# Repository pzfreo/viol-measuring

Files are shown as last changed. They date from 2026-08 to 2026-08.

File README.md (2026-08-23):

# A tap-testing rig that fits your instrument

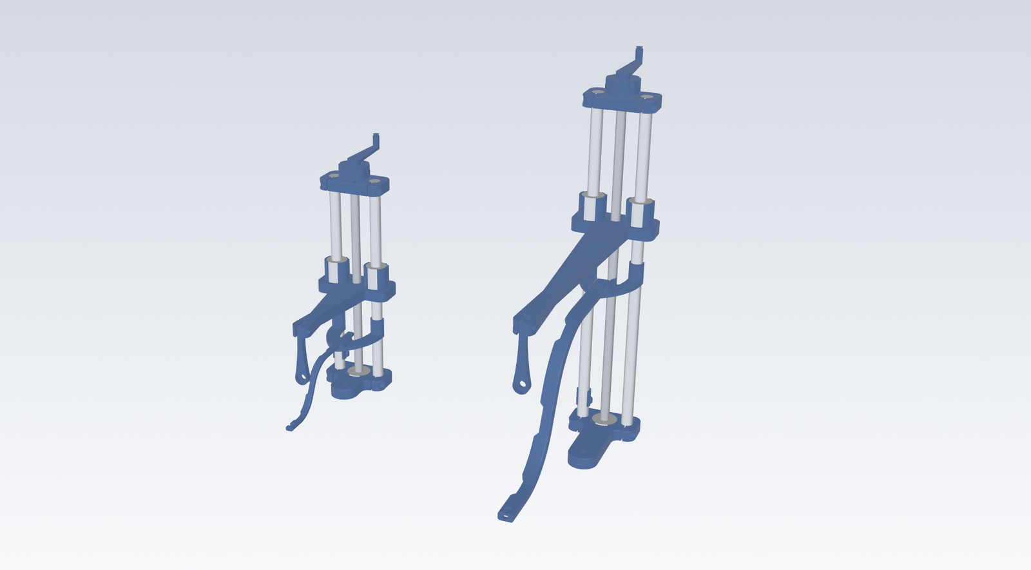
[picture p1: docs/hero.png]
The same rig built for a violin and for a cello


*The same rig, printed for a violin (left) and a cello (right) — same rods,
same bearings, same leadscrew, same clamp hardware. Nothing was redrawn: you
give it the instrument's dimensions and every part follows.*

---

This is [Luca Jost's General Acoustic Measurement Setup][upstream] rebuilt so
that it scales. His rig is a lovely piece of design: a printed column with a
sliding arm, a pendulum hammer that taps the belly at the same speed every
time, and a microphone on a curved arm beside the ribs. It is dimensioned for a
violin.

If you work on violas da gamba, cellos, or anything else with deeper ribs and a
wider lower bout, those dimensions do not fit. This version asks you for the
instrument instead:

```
body length 660    ribs 125    lower bout 380
```

and works out the rest — how far the arm must reach, how high the tap point
sits, how tall the column needs to be, and where the hammer pins.

## Which instrument?

| preset | body | ribs | lower bout | tap point | reach | column |
|---|---|---|---|---|---|---|
| `violin` | 355 | 30 | 208 | 45 up | 106 out | 200 |
| `viola` | 410 | 34 | 240 | 50 | 122 | 200 |
| `treble viol` | 370 | 62 | 230 | 80 | 117 | 250 |
| `tenor viol` | 490 | 88 | 290 | 108 | 147 | 250 |
| `bass viol` | 660 | 125 | 380 | 147 | 192 | 300 |
| `cello` | 755 | 114 | 440 | 139 | 222 | 300 |

All dimensions in mm. Every preset runs on **Luca Jost's hardware** — ⌀10
aluminium rods, an M8 leadscrew, LM10UU linear bearings, 608 thrust bearings,
M4 clamp screws. Only the rod length changes.

The `violin` preset reproduces his original rig. Every part was measured back
off his mesh files and rebuilt to match — if you want to know how closely, and
where it does not, that is in [FIDELITY.md](FIDELITY.md).

The viol figures are mid-range for surviving consort instruments, which vary far
more than the violin family does. If yours differs, see
[Changing the numbers](#changing-the-numbers).

## Making one

You need [uv](https://github.com/astral-sh/uv), or any Python 3.10+ with pip.

```bash
git clone https://github.com/pzfreo/viol-measuring
cd viol-measuring
uv venv --python 3.12 .venv
uv pip install --python .venv/bin/python build123d numpy

.venv/bin/python tools/export_all.py "bass viol"
```

That writes all eleven parts as STL and STEP into `export/bass_viol/`, plus the
whole rig assembled as a single STEP so you can look it over before spending a
weekend printing. It also prints the rig's key dimensions, so you can check them
against your instrument first. Use any preset name from the table; `violin` is
the default.

**Everything prints without support.** The cross-bolt holes are teardrop-shaped
for exactly that reason, and each part is oriented so a flat face is the build
surface. Three parts need a print pause to capture a nut — the exported bill of
materials says which, and when.

## What to buy

**[BOM.md](BOM.md)** has the full list for the cello / bass viol rig: printed
masses, exact bolt lengths, bearing designations and print orientations, all
generated from the model so it cannot drift from the geometry. Regenerate it for
any other instrument:

```bash
.venv/bin/python tools/make_bom.py "tenor viol"
```

The bought-in parts are Luca Jost's [original list][upstream] — two aluminium
guide rods, a threaded rod, linear bearings, two 608 bearings, M4 hardware,
electret microphones and a Behringer UCA-202. His README has purchase links, and
for a larger rig the only change is the length of the rods and the leadscrew.

## One rig for more than one instrument

A bass viol and a cello want **the same rig**: same rods, same leadscrew, same
300 mm column, same plates and carriage. They differ in exactly one thing the
assembled rig cannot already adjust — 30 mm of hammer reach. Everything else is
a setting: tap height is the crank, the microphone arm slides in its fins, and
the holder clips anywhere on the rods.

So build one, and give the arm a pivot hole for each:

```bash
.venv/bin/python tools/export_all.py "bass viol+cello"
```

Move the pin, wind the crank, and it is set for the other instrument.

## Four things worth knowing before you measure

**Bolt it down.** The three counterbored holes in the base are not feet — they
take M3 screws into a board. Free-standing, the violin rig tips under about 48 g
applied to the end of the arm and the cello rig under 56 g; that is a hand
resting on it. This is true of the original rig too, not something the larger
sizes introduced. Bolted to a board it is not close.

**Check your frequency range.** The measurement template that ships with the
original (`ref/upstream/GMS_template.txt`) plots from 200 Hz. A cello's A0 air
mode sits at roughly 93–120 Hz, and a bass viol's will be similar — *below the
bottom of the default plot*. The single most diagnostic low mode would not be on
screen. The 0.3 s sample window is also coarse for a sharp air mode. Both want
changing for anything larger than a viola.

**The hammer hangs on two cone points.** The two M4 × 5 grub screws are not
an afterthought — they *are* the pivot. One threads into each fork prong, and
their tapered tips seat in the rim of the 1.5 mm hole through the hammer's
tail, so the hammer swings on two cones rather than turning on a pin. Wind
them in until it just swings freely. Buy the tapered-tip ones: a flat or cup
point has nothing to seat in.

**This is not a free-free measurement.** The rig lays the instrument on its back
on the bench. Modal work normally supports the instrument on foam or hangs it on
elastic, precisely to avoid the bench damping it. For a violin the difference is
small; for a cello-sized instrument resting its ribs on a bench it is
proportionally larger. Worth one controlled comparison before trusting absolute
numbers at the large end.

## Changing the numbers

If your instrument is not one of the presets, or you have measured your own, one
line does it:

```python
from gams import Instrument, Rig

my_viol = Instrument("my bass", body_length=680, rib_depth=132,
                     arching=24, lower_bout=395)

print(Rig(my_viol).summary())
```

That prints the rig those four numbers imply. Everything else — reach, tap
height, column height, arm section — follows.

The fits are adjustable too, if your printer runs tight or loose. The one that
matters most is the slot the microphone arm slides in: the original ships the
arm in ±0.05, ±0.10 and ±0.15 mm widths for exactly this reason. Here it is a
single number (`fits.arm_slot`, default 0.06 mm) rather than four models.

## Before you print: what is proven and what is not

**The violin preset is his design**, built and iterated in practice. Everything
below applies to the larger sizes.

**None of the larger presets has been printed or used.** How the arm section
grows with reach, how the microphone arm's bend stretches, where the hammer
pins — none of that is in his design, because his design is for a violin. They
are a considered starting point, not a proven rig.

**The larger rigs are soft, and I have not fixed it.** At a cello's reach the
printed slider arm carries 91% of the movement at the tap point, and the rig's
first mode lands near 52 Hz — below a cello's A0 at about 100 Hz, so the rig can
ring inside the band you are trying to measure. What would help is a deeper arm
section, since stiffness goes as the cube of depth. See
[FIDELITY.md](FIDELITY.md#the-hardware-ladder-and-why-it-is-gone) for the
working, including a rule this repo used to have that did not survive it.

**There is no published rig at this size to check against.** Joseph Curtin's
[Impulse Measurement Rig][curtin-rig], the reference instrument in this field,
covers *"violins and violas of any size"* and does not do cellos.

## Sources and further reading

If you are new to this, start with Gough — it is the clearest overview of what
you are actually measuring and why.

**Violin family acoustics**

- Colin Gough, [*Violin Acoustics*][gough-at], Acoustics Today (2016) —
  [PDF][gough-pdf], [supplementary text][gough-supp], [media][gough-media]
- Colin Gough, [*Violin acoustics: an introduction and recent
  developments*][gough-musica] (MusICA seminar); his site: [colingough.com][gough-site]
- Jim Woodhouse, [*Euphonics: the science of musical
  instruments*][euphonics] — the online reference work; see especially
  [signature modes and formants][euphonics-modes] and [experimental modal
  analysis][euphonics-ema]
- George Bissinger's papers and the Strad3D datasets: [strad3d.org][strad3d]
- [Modal analysis of violins and cellos][asa-cello], Acoustical Society of
  America — one of the few sources giving cello mode frequencies

**Measurement practice**

- [VSA-Oberlin Acoustics Workshop][oberlin] and its
  [YouTube channel][oberlin-yt] — the annual gathering where most of this is
  worked out
- Joseph Curtin, [Impulse Measurement Rig][curtin-rig] — the commercial
  reference rig; useful for what it specifies (a few-gram impulse hammer, an
  omnidirectional condenser mic, meaningful data to 7 kHz)
- [ObiApp][obiapp], the free analysis software by Chris Rogers and Joseph
  Curtin that goes with it
- George Stoppani's [modal analysis software][stoppani] — acquisition, mode
  fitting, mode shapes and animation; widely used by makers
- Martin Schleske on [modal analysis][schleske] and [sound analysis
  method][schleske-method]
- [Support conditions for free boundary-condition modal testing][free-free] —
  why foam and elastic suspension are the norm

There is more detail, including the numbers behind the frequency-range warning
above, in [`REFERENCE.md`](REFERENCE.md).

## Credit

The design is **Luca Jost's**. The column, the pendulum hammer, the sliding arm,
the curved microphone arm, the split clamps, the choice of hardware — all of it
is his, and it is a genuinely good piece of design that repaid careful
measurement. This repository only re-expresses it as parameters so it can be
made larger.

His original: [luca-jost-violins/General-Acoustic-Measurement-Setup][upstream].
Please start there, and use his README for the parts list and purchase links.

## Licence

MIT, matching the original. See [LICENSE](LICENSE).

*(A note for Luca, if you find this: the `LICENSE` in your repository still has
the placeholder `[year] [fullname]` where the copyright line should be — that is
[issue #1][upstream-issue] on your repo. Filling it in would make it easier for
people to build on your work with confidence.)*

[upstream]: https://github.com/luca-jost-violins/General-Acoustic-Measurement-Setup
[upstream-issue]: https://github.com/luca-jost-violins/General-Acoustic-Measurement-Setup/issues/1
[gough-at]: https://acousticstoday.org/violin-acoustics-colin-e-gough/
[gough-pdf]: https://acousticstoday.org/wp-content/uploads/2016/06/Gough.pdf
[gough-supp]: https://acousticstoday.org/supplementary-text-violinacoustics-colin-e-gough/
[gough-media]: https://acousticstoday.org/violin-acoustics-media/
[gough-musica]: https://www.musica.ed.ac.uk/archive/2017/colin-gough/
[gough-site]: http://colingough.com/
[euphonics]: https://euphonics.org/
[euphonics-modes]: https://euphonics.org/5-3-signature-modes-and-formants/
[euphonics-ema]: https://euphonics.org/10-5-experimental-modal-analysis/
[strad3d]: https://strad3d.org/articles.html
[asa-cello]: https://acoustics.org/pressroom/httpdocs/135th/rossing.htm
[oberlin]: https://josephcurtinstudios.com/research/oberlin-workshop/
[oberlin-yt]: https://www.youtube.com/@oberlinacousticsworkshop9137
[curtin-rig]: https://josephcurtinstudios.com/research/measurement-rig/
[obiapp]: https://sites.google.com/view/oberlinacoustics/home
[stoppani]: http://www.stoppani.co.uk/Technical.htm
[schleske]: https://www.schleske.de/en/research/introduction-violin-acoustics/modal-analysis.html
[schleske-method]: https://www.schleske.de/en/research/introduction-violin-acoustics/sound-analysis/method.html
[free-free]: https://www.osti.gov/servlets/purl/1266149

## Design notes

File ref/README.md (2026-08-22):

# Reference material

`upstream/` holds Luca Jost's original `.3mf` parts, vendored unchanged from
[General-Acoustic-Measurement-Setup][upstream] (MIT). Everything in this
rebuild was measured from these, and the generated fingerprint suites in
`tests/fingerprint/` are checked against them.

Three directories are **not** in the repository because they are derived from
`upstream/` and are large. Regenerate them when you need them:

```bash
# STL copies of the reference parts, used to generate the fingerprint suites
PYTHONPATH=tools python tools/3mf_to_stl.py

# four-view renders of each reference part
PYTHONPATH=tools python tools/render_mesh.py

# cross-sections through a part, for reading dimensions off it
PYTHONPATH=tools python tools/section_mesh.py "ref/upstream/01 Base.3mf" Z "0.5,2,5,8" out.png
```

The other tools in `tools/` read the same references directly:

| tool | what it does |
|---|---|
| `probe_3mf.py` | bounding boxes and mesh statistics |
| `features.py` | fits circles to a cross-section — hole centres and diameters |
| `occupancy.py` | material-vs-void map on a plane, when an outline is ambiguous |
| `diff_mesh.py` | where a rebuilt part differs from its reference |
| `volume_diff.py` | localises that difference by layer |
| `arcfit.py` | decomposes a section outline into lines and arcs |
| `revolve_profile.py` | recovers the profile of a turned part |
| `stability.py` | centre of gravity and tipping loads for an assembly |

[upstream]: https://github.com/luca-jost-violins/General-Acoustic-Measurement-Setup

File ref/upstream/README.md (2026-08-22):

# General-Acoustic-Measurement-Setup

This is the universal acoustic measurement setup for musical instrument makers. Currently supported instruments are: the violin, the viola

This repository will provide .3mf files for FDM-3D-printing of the necessary parts, a list of additional parts to buy and guides for making and using the setup.

Here is a complete list of the required parts. Please note that I haven't checked for best price or availability. This is just to help you with more details about the parts. Also for some of the electronic components I could not find exact products as of yet, so there are some questionmarks around the links:

| Part | Count | Link (US) | Link (GER) |
| --- | ----- | ---| --- |
| 10 mm Diameter, 200 mm long aluminium rods | 2 | [here](https://www.amazon.com/dp/B0BNQ4Q1QQ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)  |[here](https://www.amazon.de/dp/B07K7MM3NH?ref_=ppx_hzsearch_conn_dt_b_fed_asin_title_1&th=1) |
| 210 mm long M8 threaded rod | 1 | [here](https://www.amazon.com/dp/B08FQL7LXV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)  | [here](https://www.amazon.de/Lun-Fix-Gewindestange-Festigkeitsklasse-Gewindestift/dp/B0C8HVDMVJ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) |
| 10 mm ID, 19 mm OD linear bearings | 2 | [here](https://www.amazon.com/-/de/dp/B0D4J1PK9P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)  | [here](https://www.amazon.de/dp/B09DFGZD8N?ref_=ppx_hzsearch_conn_dt_b_fed_asin_title_1) |
| 8 mm ID, 22 mm OD ball bearings | 2 | [here](https://www.amazon.com/-/de/dp/B08L8795LS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)  | [here](https://www.amazon.de/dp/B08K936Y1Z?ref_=ppx_hzsearch_conn_dt_b_fed_asin_title_1) |
| 10 mm long M4 cylinder head bolts | 4 | [here](https://www.amazon.com/-/de/dp/B0BNHGCBGP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)  | [here](https://www.amazon.de/dp/B07YWD33YT?ref_=ppx_hzsearch_conn_dt_b_fed_asin_title_2&th=1) |
| M4 nuts | 4 | [here](https://www.amazon.com/dp/B0CJR56V5G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)  | [here](https://www.amazon.de/dp/B0868PHTDC?ref_=ppx_hzsearch_conn_dt_b_fed_asin_title_1) |
| 5 mm long M4 tapered tip grub screws | 2 | [here](https://www.amazon.com/-/de/dp/B09SG5QVCL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)  | [here](https://www.amazon.de/dp/B0CJ5BV79K?ref_=ppx_hzsearch_conn_dt_b_fed_asin_title_3) |
| M8 nut | 1 | [here](https://www.amazon.com/dp/B0CQJJ8Z61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)  | [here](https://www.amazon.de/dp/B0CNRSB225?ref_=ppx_hzsearch_conn_dt_b_fed_asin_title_1&th=1) |
| M8 locking nuts | 3 | [here](https://www.amazon.com/dp/B0CPJH281Y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)  | [here](https://www.amazon.de/dp/B0CNRGYSQL?ref_=ppx_hzsearch_conn_dt_b_fed_asin_title_1&th=1) |
| 200 mm long 0.14 mm² wire, 1.1 mm OD | 4 | [here](https://www.amazon.com/dp/B07G2HFCS1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)  | [here](https://www.conrad.de/de/p/bkl-electronic-1501022-10-litze-liy-1-x-0-14-mm-gruen-10-m-1521222.html) |
| 10 mm long thin wire (e.g. 34 AWG) | 4 | [?here?](https://www.amazon.com/BNTECHGO-AWG-Magnet-Wire-Transformers/dp/B07J4P14JB?th=1)  | [here](https://www.nevs-controller.de/reparatur-und-wartung/taster-kabel-led/kabel-flexibel-34awg-meterware.html) |
| Cinch plugs | 4 | [here](https://www.amazon.com/dp/B079TM1682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)  | [here](https://www.amazon.de/dp/B0B4SG16J2?ref_=ppx_hzsearch_conn_dt_b_fed_asin_title_1&th=1) |
| 9.7 mm x 4.7 mm electret microphones | 2 | [?here?](https://www.amazon.com/-/de/dp/B0CKRZXHHL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)  | [here](https://www.amazon.de/dp/B08F34VY23?ref_=ppx_hzsearch_conn_dt_b_fed_asin_title_1) |
| 6 mm x 2.7 mm electret microphones | 2 | [?here?](https://www.amazon.com/-/de/dp/B0CKS1D6CF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)  | [here](https://www.amazon.de/dp/B00OK6GPWC?ref_=ppx_hzsearch_conn_dt_b_fed_asin_title_1) |
| Behringer UCA-202 Audio Interface | 1 | [here](https://www.amazon.com/-/de/dp/B000KW2YEI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)  | [here](https://www.amazon.de/Behringer-U-Control-UCA202-Interface-Soundkarte/dp/B000KW2YEI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) |
| 4.7 kΩ resistors | 2 | [here](https://www.amazon.com/-/de/dp/B072BL2VX1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)  | [here](https://www.amazon.de/Elegoo-Widerst%C3%A4nde-Sortiment-St%C3%BCck-Metallfilm/dp/B072BHDBDG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) |
| 1 ㎌ ceramic capacitors | 2 | [here](https://www.amazon.com/-/de/dp/B085RDTCCV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)  | [here](https://www.amazon.de/dp/B087785H1J?ref_=ppx_hzsearch_conn_dt_b_fed_asin_title_5) |

Shorthands:

ID = Inner Diameter

OD = Outer Diameter

AWG = American Wire Gauge

kΩ = kiloohm

㎌ = microfarad

Here is a complete list of the required tools and consumables:

| Tool                                     |
| -------------                            |
| Scissors                                 |
| Side cutters                             |
| Small knife                              |
| Wire strippers                           |
| Pliers                                   |
| Screwdriver with M2, M3 and Phillips bits|
| 13 mm wrench                             |
| Soldering iron                           |
| Heat gun                                 |
| Multimeter                               |
| Poking tool                              |
| Small clamp                              |
| Plastic straw                            |

| Consumable | Link (US) | Link (GER) |
| --- | ---  | --- |
| Solder | [here](https://www.amazon.com/dp/B076QF1Y85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)  | [here](https://www.amazon.de/dp/B07Z7BVKXQ?ref_=ppx_hzsearch_conn_dt_b_fed_asin_title_10&th=1) |
| Soldering grease | [here](https://www.amazon.com/-/de/dp/B09P89PKP3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)  | [here](https://www.amazon.de/FELDER-L%C3%B6tfett-L%C3%B6tmittel-Solder-L%C3%B6tpaste/dp/B01822CUO6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) |
| Heat shrink tubing | [here](https://www.amazon.com/-/de/dp/B072PCQ2LW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)  | [here](https://www.amazon.de/dp/B0778D22WM?ref_=ppx_hzsearch_conn_dt_b_fed_asin_title_1) |
| Two part epoxy | [here](https://www.amazon.com/-/de/dp/B07W2WVHZW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)  | [here](https://www.amazon.de/dp/B0BP8DB3LL?ref_=ppx_hzsearch_conn_dt_b_fed_asin_title_1) |

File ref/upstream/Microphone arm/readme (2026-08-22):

These are models for different microphone arm widths. Depending on your printer's tolerances, the standard microphone arm might be too loose or too tight. The models marked with a minus are less wide so would provide a looser fit than the normal model. Those marked with a plus are wider so would provide a tighter fit. If you are using a printing service, I would recommend printing a few variations, as it should not be much more expensive and could make things easier for you. If you have a too loose or too tight fit and printing another microphone arm is not an option, you can either add a thin layer of CA glue to one side of the microphone arm or shave off small amounts of material from the microphone arm using a plane or sandpaper to achieve a tighter or looser fit respectively.

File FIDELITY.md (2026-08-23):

# How close is it, and how do I know?

This is the working behind the claim on the front page: that the `violin`
preset reproduces [Luca Jost's rig][upstream] rather than merely resembling it.
None of it is needed to build one. It is here so the claim can be checked, and
so the places it does not hold are written down rather than glossed.

## What was compared, and how

Each of his eleven `.3mf` files was moved into the frame its parametric
counterpart is built in, and then compared against it. There is a generated
geometric-equivalence suite per part in `tests/fingerprint/`, built with
[cad-fingerprint][fingerprint], holding an embedded copy of his mesh and
checking volume, surface area, centre of mass, the full inertia tensor,
cross-sections and point-by-point surface deviation.

```bash
python tools/report.py       # every part, measured, whether it passes or not
```

The suites only print a value when a check fails, which tells you nothing about
how much room a passing part had. `tools/report.py` calls the same routines
directly so every part reports a number either way.

## Where it stands

| part | volume | surface deviation | worst | centre of mass |
|---|---|---|---|---|
| Base | −0.37% | 0.383 mm mean | 0.804 / 3.07 | 0.027 mm |
| Top | −0.10% | 0.010 | 0.286 / 0.30 | 0.013 |
| Slider | −0.07% | 0.260 | 2.179 / 3.24 | 0.085 |
| Microphone holder | +0.04% | 0.007 | 0.060 / 0.30 | 0.021 |
| Microphone arm | +0.58% | 0.172 | 1.293 / 2.00 | 0.105 |
| Cable clip | +0.06% | 0.016 | 0.217 / 0.30 | 0.013 |
| Hammer | −0.14% | 0.098 | 0.536 / 1.24 | 0.023 |
| Knob | −0.02% | 0.004 | 0.040 / 0.30 | 0.003 |
| Knob handle | +0.03% | 0.001 | 0.024 / 0.30 | 0.002 |
| Knurled sleeve | +0.20% | 0.006 | 0.250 / 0.30 | 0.050 |
| Handheld hammer | −0.16% | 0.095 | 0.637 / 1.43 | 0.016 |

**All eleven are inside every tolerance.** Worst volume error 0.58%, worst
centre of mass 0.105 mm, every bounding box within 0.010 mm. The tolerances are
not comparable between parts — cad-fingerprint scales each from how well that
part's reference mesh decimated, which is why the slider is allowed 3.24 mm and
the knob 0.30.

The *fits* are asserted separately, by ordinary tests: the crank socket clears
the knob post, the sleeve spins on its pin but cannot come off, the hammer
swings free in the fork, the bearing bores are a zero-clearance press fit on a
⌀19 LM10UU, and no two parts interfere in any preset.

## Volume is the weak test

It was also the one this rebuild used for far too long, and it hid real errors.
The hammer sat at +1.1% by volume while having a fork where the reference has a
counterbored bore, a centred square core where it has an offset round channel,
and a sampled taper table where it has a single 200 mm arc. Three substantial
errors that nearly cancelled.

What catches that is surface deviation, and — for anything with a hole in it —
looking at the part. The knurled sleeve passed every metric with small tabs of
material hanging off its top rim, because a row of its diamond crossings landed
exactly on the edge. No number objected. That was spotted by eye in a CAD
viewer, and it is the honest limit of everything on this page.

## What the measurement turned up

Fitting primitives and reading the residual, rather than storing sampled
points, is what turns a good-enough curve into his actual number. Where a fit
comes back at two microns, that is a construction and not a coincidence.

- The **hammer's outline is three arcs** — a ⌀12 round head, a ⌀5 round tail,
  and an R200 arc tangent to both, fitting to 0.002 mm. Not a taper and not a
  spline. Its internal channel is round, offset 1 mm from the centre plane,
  straight to Z=36 and then out through one face on an R38 arc.
- The **microphone holder's arch is two very large arcs**, R54.7 outside and
  R45.4 in, struck from centres out on the rod axis and meeting at a point that
  is then rounded off. They fit to 0.01 mm, so the arch height falls out of them
  rather than being typed in.
- The **knob's knurl is nine circles that all pass through its axis**, struck at
  half the knob's radius from centres half the radius out. Their union is the
  body. It fits within 0.02 mm where the best single cutter managed 0.30.
- **Every teardrop is struck as tangents to its hole**, which is what puts the
  sides at exactly 45° — the steepest overhang a printer bridges without
  support. A triangle from the hole's diameter, which is what this rebuild had,
  gives whatever angle the apex constant happens to produce.
- The **clamp nut slots close as a 30° gable**, so the nut meets a wedge and
  settles onto the bolt axis instead of sitting anywhere across the slot.
- Both plates **relieve the thrust bearing's inner race**, stepping the bore
  22 → 12 → 9 mm. Without it the plate bears on the race the leadscrew turns in.
- The **microphone arm** is a rounded rectangle with an obround channel inside
  it — not the other way round, which costs 9% of the section area. Its S-bend
  is an arc, a straight and a second arc, tangent throughout. Its three side
  windows are spaced along the arm rather than along its reach, so the middle
  one spans barely 2 mm of reach for its 10 mm of arm.
- The **microphone seat is a plain ⌀6.00 hole**, fitting to 0.006 mm — which
  matches the 6 × 2.7 mm electret in his bill of materials.
- The **cable enters the slider through a cone of exactly 15°** in the
  carriage's front face, and runs out along the arm to the fork on a ⌀3.5 bore
  whose axis stays at mid-thickness the whole way.
- The **knurled sleeve is a diamond**: two families of eight helical grooves at
  13.3° of twist per millimetre. Where the crossings sit along its height is a
  separate thing to get right, and getting it wrong puts tabs on the rim.
- The **bearing seat** in both plates is not a round pocket but a disc flatted
  to exactly 22.0 mm across, so the flats locate the 608 — far easier to print
  to size than a bore.

## The hardware ladder, and why it is gone

This rebuild used to step the guide rods and leadscrew up with reach: ⌀12 above
the violin, ⌀16 for bass viol and cello, M10 instead of M8. That was my rule,
not his, on the argument that a printed cantilever on ⌀10 rods deflects enough
at a cello's reach to move the tap point between taps.

Working out where that movement actually comes from says otherwise:

```bash
python tools/stiffness.py
```

| cello rig, 300 mm column | movement at the tap point | |
|---|---|---|
| printed slider arm | 394 µm | 91% |
| ⌀10 rods | 40 µm | 9% |
| ⌀16 rods | 9 µm | 2% |

Going ⌀10 → ⌀16 buys 31 µm out of 434. In stiffness the arm is 1.9 N/mm at the
tap point and the ⌀10 rods 19.3 — springs in series, so the soft one decides,
and the rig's first mode moves only from **52 Hz to 55**. The leadscrew was
worse: it carries about 1 N, and an M8 at 300 mm buckles near 2000 N, so
stepping it to M10 was three orders of magnitude of nothing — and it pulled the
thrust bearing up with it. One invented rule dragged two more behind it.

The ladder is gone. Every preset now runs on his hardware, and the plates went
back to his 60 × 30 with it, which took 94 g of filament off the cello rig.

**The finding that matters is the one the ladder was obscuring:** at 52 Hz the
larger rigs sit below a cello's A0 at about 100 Hz, so the rig can ring inside
the band being measured. Fixing that means a deeper arm section, since stiffness
goes as the cube of depth. It has not been done.

## The two M4 grub screws

For a long time this was the one thing in his design I could not account for. I
looked for a threaded hole in the bearing tubes, found none, and wrote it up as
an unresolved gap. It is not a gap, and the answer is better than a fixing.

**They are the hammer's pivot.** One threads into each fork prong; their cone
points seat in the rim of the 1.5 mm hole through the hammer's tail, so the
hammer hangs on two cones rather than turning on a pin. The measurements:

| | |
|---|---|
| fork prong hole | ⌀3.925, right through — *under* M4's 4.0 major diameter, so the screw cuts its own thread |
| prong thickness | 4.705 mm, so an M4 × 5 stands 0.295 proud of the inner face |
| hammer's hole | ⌀1.496 through — far too small for a bolt; it is a seat for the cone tips |
| both | coaxial on X at Y = 106.5, Z = 5.0 |

Every detail that had puzzled me separately falls out of it: why the hammer's
hole is only 1.5 mm when I was hunting for a pivot bore; why there are exactly
two screws; why 5 mm, which is the length that gives cone engagement rather than
a clamp; why *tapered tip* and not flat or cup; and why his published parts list
has **no hammer pivot bolt** — four M4 × 10 for the rod clamps, four M4 nuts, two
M4 × 5 grubs, and nothing else.

It is also the right answer mechanically. Two cones is about as little friction
as a printed pivot can have, and a stiff pivot damps the impulse the rig exists
to measure.

This repo had modelled the prong hole as a ⌀4.0 clearance hole and the BOM had
invented an M4 × 25 bolt and nut to go through it. Both are corrected: the hole
is now the thread-forming 3.925 he uses, and the fastener is gone.

## Known gaps

**Above violin size, the scaling rules are mine** and none of those presets has
been printed. See the front page for what that means in practice.

## Tooling

Everything here is reproducible from the repository.

| | |
|---|---|
| `tools/report.py` | every part measured against his mesh |
| `tools/stiffness.py` | where the compliance lives, and the first mode |
| `tools/stability.py` | centre of gravity and what it takes to tip it over |
| `tools/interference.py` | no two parts occupying the same space |
| `tools/compare_sections.py` | his section and mine on the same plane |
| `tools/overlay.py` | the same, drawn on top of each other |
| `tools/xsection_ascii.py` | a filled section as text, when solid-or-void must be unambiguous |
| `tools/find_bores.py` | every cylindrical void in a reference mesh |
| `tools/make_locals.py` | his `.3mf` files moved into each part's own frame |

Two bugs in cad-fingerprint were found doing this and are filed upstream:
[#5][fp5], cross-section area adds holes instead of subtracting them; and
[#6][fp6], the radial profile compares the nearest surface against a reference
taken from the outer one, so every hollow part fails every ray that crosses a
cavity. Between them they accounted for 194 of 206 remaining check failures,
which is why `tools/report.py` leaves both out.

[fingerprint]: https://github.com/pzfreo/cad-fingerprint
[fp5]: https://github.com/pzfreo/cad-fingerprint/issues/5
[fp6]: https://github.com/pzfreo/cad-fingerprint/issues/6

[upstream]: https://github.com/luca-jost-violins/General-Acoustic-Measurement-Setup

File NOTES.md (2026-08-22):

# Rebuild notes

Goal: a parameterisable build123d model of the GAMS rig, replacing the fixed
`.3mf` files from luca-jost-violins/General-Acoustic-Measurement-Setup.

## Method

The upstream parts are meshes only — no CAD source — so dimensions are
recovered from the meshes and the rebuild is verified against them:

1. `ref/upstream/` — vendored upstream `.3mf` (MIT).
2. `tools/probe_3mf.py` — bounding boxes.  All 11 parts share one assembly
   coordinate frame, so their positions give the assembly directly.
3. `tools/3mf_to_stl.py` → `ref/stl/` — STL for fingerprinting.
4. `tools/render_mesh.py` → `ref/render/` — 4-view renders.
5. `tools/section_mesh.py` / `tools/features.py` → cross-sections and fitted
   circles (centre + diameter) at any plane.
6. `cad-fingerprint <stl> -o tests/test_XX.py` — pytest geometric equivalence
   suite per part; the parametric code must pass it at default parameters.

## Assembly frame (from bounding boxes, mm)

| Part | X | Y | Z |
|---|---|---|---|
| 01 Base | -30..30 | -15..42.50 | 0..10 |
| 02 Top | -30..30 | -15..15 | 190..200 |
| 03 Slider | -35..35 | -15..110.90 | 95..124 |
| 04 Microphone holder | -26.25..26.25 | -3..45.63 | 49.5..67.5 |
| 05 Microphone arm | -3.125..3.125 | 14.68..133.67 | 12.5..56.2 |
| 06 Cable clip | 13.75..26.25 | -12.50..3 | 20..35 |
| 07 Hammer | -6..6 | 103.5..109.5 | 49.00..104.5 |
| 08 Knob | -14..14 | -14..14 | 202..218 |
| 09 Knobhandle | -6..6 | -48.00..6 | 215..229 |
| 10 Knobhandleknurl | -3..3 | -48..-42 | 218.5..227.5 |
| 11 Handheld hammer | same bbox as 07 | | |

Z is the column axis; the M8 leadscrew is on X=Y=0.

## Dimensions recovered so far

**01 Base** (Z 0..10, plate 10 thick)
- Outline 60 wide, Y -15..15 rounded rect, plus a lobe on +Y: arc centred
  (0, 30) reaching Y=42.50 (r = 12.50).
- Leadscrew bore on axis: r=4.50 at Z=0.5, opening to r=6.00 by Z=2, then a
  608 bearing pocket (bbox 22.13 x 26.00) from about Z=4 to the top face.
- Rod bores at (+/-20, 0) — merged with the clamp slots in section, radius
  still to confirm.
- Clamp slots: 3.5 wide at X = +/-(14.7..18.2), running in from Y=15.
- 3 x M3 holes: (+/-24, -9) and (0, 30), d=3.50, counterbored to d=5.50 at
  Z=9.5.
- 4 x curved lightening slots around the leadscrew.

## Status: complete

Every part is within 1.9% of the upstream reference by volume, against a 3%
target, and every one builds as a single valid solid at all five instrument
presets (55 builds).

| part | built | reference | diff |
|---|---|---|---|
| 01 Base | 16780.4 | 16749.2 | +0.19% |
| 02 Top | 10735.3 | 10650.4 | +0.80% |
| 03 Slider | 29416.0 | 29652.7 | -0.80% |
| 04 Microphone holder | 4471.9 | 4500.2 | -0.63% |
| 05 Microphone arm | 2198.8 | 2193.6 | +0.24% |
| 06 Cable clip | 558.9 | 558.5 | +0.07% |
| 07 Hammer | 1703.1 | 1684.7 | +1.09% |
| 08 Knob | 5759.3 | 5676.8 | +1.45% |
| 09 Knobhandle | 1419.6 | 1423.5 | -0.27% |
| 10 Knobhandleknurl | 80.7 | 79.2 | +1.90% |
| 11 Handheld hammer | 1752.0 | 1766.1 | -0.80% |

74 tests pass. They assert fits, not just shapes: the handle socket clears the
knob post, the grip spins on its pin but cannot come off, the hammer shaft
swings free in the slider fork, the microphone channel takes a 6 mm electret,
the bearing bores are a zero-clearance press fit.

### The microphone arm, and a correction

An earlier pass recorded that the arm "tapers" and was modelled at a constant
section as an approximation. **Both halves of that were wrong**, and the real
structure matters:

- The outer section is **constant**, and it is an **obround** — ends fully
  rounded at radius t/2, not a rounded rectangle. That distinction alone is
  ~9% of the arm's volume.
- What changes along the arm is that the **+X wall is cut away in two short
  windows** (Y 58.5..70.5 and 109.5..120.5), so the cable is laid into the
  channel from the side rather than threaded through it.
- Everywhere else — including the whole S-bend — the section stays a **closed
  box**. That is the important part: an open section is far softer in twist
  than a closed one, and the original deliberately keeps the box closed through
  the bend, where the arm is longest and least supported.

The first model had it as an open C for the whole run past the clamp with a
bore sized to make the volume come out right. It hit the number and got the
structure backwards.

## What the reference gave up, part by part

- **Base/Top**: bearing seat is a rim-sized disc flatted to exactly 22.0 across
  X — the flats locate the 608, which is far easier to print to size than a
  round pocket. Lightening is mirror-symmetric about both axes, not four-fold.
- **Slider**: the arm necks to a waist at 0.755 of reach, and each bearing post
  is L-shaped in section, wide at the bearing and stepping in at the rim.
- **Cable clip**: it is one ring twice, the second dropped by exactly one outer
  radius so the two touch.
- **Holder**: the arch is a superellipse, n = 1.66 outer and 1.64 inner.
- **Hammer**: 07 and 11 are the same part; 11 simply has no pivot slot.

## The microphone subsystem did not scale (fixed)

The first assembly looked right for the violin and was broken for every gamba:
the microphone arm sat at violin height (Z 12.5..56.2) on a 300 mm column, and
the holder was at Z 206 from a formula that had no business existing. Nothing
was literally absent — the arm and holder were simply floating, unconnected to
anything.

What was wrong, and what each is now derived from:

| was fixed at | now |
|---|---|
| `mic_arm_w` 6.25, `mic_arm_t` 3.66 | fractions of mic reach |
| channel size and offset | fractions of the arm section |
| `mic_arm_root_z` 54.35 | tap height + 9.35, i.e. just clear of the belly |
| `mic_arm_tip_z` 14.34 | the microphone height |
| `holder_z` = mic_height x 3.3 | set so the fins land on the arm's root |
| `arm_slot_w` 6.31 | arm width + 0.06 |
| `fin_h`, `fin_outer_x`, arch semi-axes | derived from the arm and the rod span |
| `handle_len` 45 | 1.607 x knob diameter |
| `clip_h`, `clip_mouth_y`, `holder_h` | multiples of rod diameter |

Two things only showed up once the gamba presets were actually built:

- **The traced bend table's Y values are absolute fractions of reach.** Making
  `mic_arm_bend_from` derived did nothing until the table was remapped onto
  each rig's own bend. Until then the bass arm's swept section folded through
  itself and the part came out as four solids.
- **The bend has to start clear of the holder.** The drop grows with rib depth
  (x3.3 from violin to bass viol) far faster than the reach does (x1.6), so the
  bend starts earlier and earlier — and on the bass rig it started *inside the
  fins gripping the arm*. `mic_arm_bend_from` now has a floor at the holder's
  forward reach.

The lesson is the same one as the slider's arm taper: **a parameter that is a
fixed number rather than a ratio does not announce itself on the preset it was
measured from.** Only building the extremes finds them.

## Stability — the rig is not free-standing, and never was

Centre of gravity computed over the whole assembly (printed parts PLA 1.24,
guide rods aluminium 2.70, leadscrew and bearings steel 7.85 g/cm3), checked
against the triangle of the three mounting points:

| preset | mass | CoG (Y, Z) | static margin | tips under, on the arm tip |
|---|---|---|---|---|
| violin | 430 g | 3.7, 101.8 | +12.7 mm | **48 g** |
| viola | 603 g | 3.9, 103.8 | +14.9 mm | 68 g |
| treble viol | 475 g | 4.1, 130.2 | +13.1 mm | 49 g |
| tenor viol | 676 g | 5.2, 139.2 | +16.2 mm | 69 g |
| bass viol | 1192 g | 6.4, 171.5 | **+21.4 mm** | **123 g** |

**The bass viol is the most stable of the five, not the least** — the outrigger
scaling with reach does its job, and the margin grows from 12.7 mm on the
violin to 21.4 mm.

But every preset tips under a load you would apply by resting a hand on the
arm: 48 g on the violin, 123 g on the bass viol. The violin preset reproduces
the upstream geometry, so **this is true of the original rig too** — it is not
something the gamba scaling introduced.

That resolves what the three mounting points are for. Each is a 3.5 mm hole
with a 5.5 x 1.0 spotface in the *top* face — an M3 socket cap head is 5.5 mm
across, so a screw drops in from above and seats there. They are bolt-down
points, not feet, and the rig wants fastening to a board or the bench.

Bolted, it is not close: a 1 kg load on the arm tip of the bass rig puts about
6 N of uplift on each rear screw, which is nothing for M3 into wood.

### A separate gap: the hammer does not scale

The hammer is 2.1 g on every preset — it is one of the few parts still sized
absolutely. Its length is `hammer_drop`, which is also fixed, so the same
impulse energy goes into a bass viol as into a violin, into a top plate several
times heavier. Whether that is enough to excite the instrument is an acoustic
judgement rather than a geometric one, so it has been left alone rather than
scaled on a guess — but it is the obvious next thing to question.

## Next, if you want it

- The assembly, driven by the shared coordinate frame the .3mf files already
  agree on: base Z 0, slider Z 95, top Z 190, knob Z 202.
- A tap test on the bare rig to find where the arm rings, before trusting the
  bass viol preset at 192 mm reach.

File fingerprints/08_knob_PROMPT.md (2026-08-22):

# Reverse-Engineer a STEP File into build123d

## Goal

Recreate the geometry in the reference STEP file as procedural build123d Python code. The test suite in `test_Knob.py` defines geometric assertions that your implementation must pass.

## Part Overview

- **Bounding box**: 28.0 × 28.0 × 16.0 mm
- **Volume**: 5676.8 mm³
- **Surface area**: 2932.9 mm²
- **Faces**: 2688 (0 BSpline / complex)
- **Primary axis**: Z

## Key Dimensions (extracted from fingerprint)

### Profile transitions

Significant cross-section area changes along the Z axis:

- At Z=213.7: area 591.2 → 113.0 mm²
- At Z=215.4: area 113.0 → 42.4 mm²

## Process

1. **Study the fingerprint data** in the test file. The reference data tells you everything about the shape:
   - `REF_FACE_INVENTORY` — every face type, area, and key dimensions (diameters, radii)
   - `REF_EDGE_INVENTORY` — every edge type, length, and radii (circle edges indicate fillets/rounds)
   - `REF_CROSS_SECTIONS` — cross-sectional area at multiple Z positions
   - `REF_RADIAL_PROFILE` — outer radius at multiple positions × angles
   - `REF_VOLUME`, `REF_SURFACE_AREA`, `REF_BBOX_*` — global properties
   - `REF_MESH` — the triangulated reference surface, used by the Hausdorff surface-deviation tests
   - `REF_INERTIA` — moments of inertia (very sensitive to mass distribution)

2. **Create your implementation** in a new file that exports a function returning a build123d `Part`.

3. **Create a conftest.py** with a fixture:
   ```python
   import pytest
   from my_implementation import create_Knob

   @pytest.fixture
   def part_under_test():
       return create_Knob()
   ```

4. **Run the tests**: `pytest test_Knob.py -v`

5. **Iterate**. Read the failures, adjust your code, repeat.

## Tips for Reading the Fingerprint

- **Cross-sections** show area vs position. Large jumps indicate transitions between features. Constant areas indicate cylindrical or prismatic sections.
- **Radial profiles** show radius vs angle at each position. Uniform radius = circular. Varying radius = sculpted/oval. `None` values mean the ray missed (bore or concavity).
- **Face inventory** lists every surface. BSpline faces are sculpted regions — you may need `fillet`, `sweep`, or `loft` operations, or accept that OCCT will approximate them as BSplines.
- **Surface deviation** (Hausdorff distance) is the catch-all: it samples points on both surfaces and measures the worst-case point-to-surface distance. If aggregate tests pass but this one fails, a local feature is in the wrong place or the wrong shape; the failure message says whether the part has excess or missing material.
- **Cylinder diameters** give you key feature sizes directly.
- **Torus faces** are fillets/rounds — the minor radius is the fillet radius.

## Build Quality Rules

The test suite includes build quality checks. Follow these rules to avoid common failures:

### After every boolean (fuse, subtract, split)
- Verify the result is a single solid. Boolean operations in build123d can return `Compound`, `ShapeList`, or multiple solids.
- Use a helper like `max(result.solids(), key=lambda s: s.volume)` to extract the largest solid if needed.
- Check for unexpected topology changes (face count, edge count).

### After every fillet
- Verify the fillet actually applied (face count should increase).
- If OCCT produces BSpline surfaces where the reference has Torus faces, consider alternative approaches (torus subtract, arcs in revolve profiles).
- Fillets on complex edge intersections (sphere-plane, cone-plane) will almost always produce BSpline approximations.

### STEP export
- Use AP203 with `STEPControl_ManifoldSolidBrep` for best compatibility.
- Run `ShapeFix_Shape` before export to catch minor geometry issues.

## What Success Looks Like

All tests passing means your procedural code produces geometry that is manufacturing-equivalent to the reference STEP file. Minor surface representation differences are OK — the tolerances are calibrated to accept these while catching real geometry errors.

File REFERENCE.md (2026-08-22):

# Reference data for sizing the rig

Gathered while checking whether the large end of this rig is pointed at the
right frequencies. The short version: **published acoustics for the violin
family stops at the viola**, so the cello is the nearest well-documented
instrument to a bass viol and is the best available proxy.

## Instrument dimensions

| | body | lower bout | rib depth | source |
|---|---|---|---|---|
| violin | 355 | 208 | 30 | trade standard |
| viola | 410 | 240 | 34 | trade standard |
| treble viol | 370 | 230 | 62 | mid-range for surviving instruments |
| tenor viol | 490 | 290 | 88 | " |
| bass viol | 660 | 380 | 125 | " |
| **cello (4/4)** | **755** | **440** | **~114** | Aitchison & Mnatzaganian; Alabaster |

A cello is dimensionally very close to a bass viol — slightly longer and wider,
slightly shallower ribs. `CELLO` is now a preset, and it builds and stands.

## Where the modes are

This is what matters for the rig, because it sets the band the arm must not
ring in and the band the software has to plot.

| mode | violin | cello |
|---|---|---|
| A0 (Helmholtz air) | ~272 Hz | **~93-120 Hz** |
| CBR | ~407 Hz | — |
| B1- / B1+ | ~462 / 551 Hz | B1 is the highest peak **below 300 Hz** |
| bridge hill | ~2.3 kHz | two hills, ~1 kHz and 2-2.3 kHz |
| bridge sway / bend / bounce | — | 1.5 / 2.2 / 3.1 kHz (Reinicke) |

Cello modes have been measured up to ~5 kHz, with 61 individual modes counted
below 1.5 kHz.

### This breaks the shipped software settings

`ref/upstream/GMS_template.txt` plots from **200 Hz** (`X Range` starts at
2.0E+2). A cello or bass viol's A0 sits at 93-120 Hz — **below the bottom of
the default plot**. The single most diagnostic low mode would simply not be on
screen.

Also `Sample time = 0.3 s`, which is 3.3 Hz of native resolution. At 93 Hz that
is 3.6% — usable but coarse for a sharp air mode. Both want changing for
anything cello-sized.

## The hammer: 2 g is right after all

I had flagged the 2.1 g hammer as suspiciously light and possibly a scaling
gap. It is not. Joseph Curtin's Impulse Measurement Rig uses a PCB 086C80
impulse hammer with "a head weighing just a few grams", tapping the bridge.
A few grams is professional practice, so the upstream hammer is deliberate.

What remains open is *energy*, not bandwidth: a few-gram head is fine for
exciting a wide band, but whether it puts enough into a cello-sized top is
untested — see below.

## Nobody else does this size

Curtin's rig — the reference instrument in this field — states it accommodates
"violins and violas of any size". **Cellos are not supported.** Strad3D's
entire dataset is violins. The ObiApp analysis software is described as being
for violins.

So extending a tap rig to cello and gamba size is not a solved problem being
reimplemented here. That is worth knowing before trusting the bass viol preset:
there is no published rig geometry to check it against.

## How large instruments are supported for modal work

Free-free conditions are the norm: softly supported on foam, or hung on
elastic/bungee. The rule of thumb is that the first flexible mode should be
about ten times the highest rigid-body mode for the support to be ignorable.

This rig assumes the instrument lies on its back on the bench, which is not a
free-free condition. For a violin the difference is small; for a cello-sized
instrument resting its ribs on a bench the contact damping is proportionally
larger. Worth a controlled comparison before trusting absolute numbers at the
large end.

## Sources

### Violin family acoustics

- Colin Gough, [*Violin Acoustics*, Acoustics Today (2016)](https://acousticstoday.org/violin-acoustics-colin-e-gough/)
  — [PDF](https://acousticstoday.org/wp-content/uploads/2016/06/Gough.pdf),
  [supplementary text](https://acousticstoday.org/supplementary-text-violinacoustics-colin-e-gough/),
  [media](https://acousticstoday.org/violin-acoustics-media/)
- Colin Gough, [*Violin acoustics: an introduction and recent developments*](https://www.musica.ed.ac.uk/archive/2017/colin-gough/) (MusICA seminar)
- Colin Gough, [colingough.com](http://colingough.com/) and [violinacoustics.com](https://violinacoustics.com/)
- Jim Woodhouse, [*Euphonics*](https://euphonics.org/) —
  [signature modes and formants](https://euphonics.org/5-3-signature-modes-and-formants/),
  [experimental modal analysis](https://euphonics.org/10-5-experimental-modal-analysis/)
- [Modal analysis of violins and cellos](https://acoustics.org/pressroom/httpdocs/135th/rossing.htm), Acoustical Society of America
- George Bissinger's papers and datasets, [strad3d.org](https://strad3d.org/articles.html)

### Measurement practice

- Joseph Curtin, [Impulse Measurement Rig](https://josephcurtinstudios.com/research/measurement-rig/)
- [VSA-Oberlin Acoustics Workshop](https://josephcurtinstudios.com/research/oberlin-workshop/)
  and its [YouTube channel](https://www.youtube.com/@oberlinacousticsworkshop9137)
- [ObiApp](https://sites.google.com/view/oberlinacoustics/home), Chris Rogers and Joseph Curtin
- George Stoppani, [acoustic analysis software](http://www.stoppani.co.uk/Technical.htm)
  — Acquisition, ModeFit, ModeShape, FRFOverlay, GS Spectrum Analyser
- Martin Schleske, [modal analysis](https://www.schleske.de/en/research/introduction-violin-acoustics/modal-analysis.html)
  and [sound analysis method](https://www.schleske.de/en/research/introduction-violin-acoustics/sound-analysis/method.html)
- [Support conditions for free boundary-condition modal testing](https://www.osti.gov/servlets/purl/1266149)

### Instrument dimensions

- [Cello measurement — Aitchison & Mnatzaganian](https://www.aitchisoncellos.com/cello-measurement/)
- [Cello specifications — Alabaster Handcrafted Instruments](https://guitars.davidalabaster.com/cello-specification-pricing/)

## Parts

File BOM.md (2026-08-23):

# Bill of materials — cello and bass viol

One rig serving **cello and bass viol**. Generated from the model by
`tools/make_bom.py`, so every mass, length and bearing size below comes
from the same parameters the parts are built from.

The hammer pins at **192 mm, 222 mm** — move the pin and wind the crank to
change instrument. Everything else is the same hardware for both.

## Printed parts

| part | qty | volume | filament | print it |
|---|---|---|---|---|
| 01 Base | 1 | 24.8 cm³ | 31 g | flat on its underside |
| 02 Top | 1 | 10.6 cm³ | 13 g | flat, bearing seat upwards |
| 03 Slider | 1 | 47.9 cm³ | 59 g | flat on its underside, tubes up - PAUSE to embed the nut |
| 04 Microphone holder | 1 | 4.9 cm³ | 6.1 g | flat on the arch |
| 05 Microphone arm | 1 | 15.2 cm³ | 19 g | on its side, channel outwards |
| 06 Cable clip | 3 | 0.6 cm³ | 2.1 g | flat, mouth upwards |
| 07 Hammer | 1 | 1.7 cm³ | 2.1 g | on its side |
| 08 Knob | 1 | 5.7 cm³ | 7.0 g | flat, hex trap down - PAUSE to embed the nut |
| 09 Knob handle | 1 | 1.4 cm³ | 1.8 g | flat, pin upwards - PAUSE to slide the knurl on |
| 10 Knob handle knurl | 1 | 0.1 cm³ | 0.1 g | on end - print this one first |
| 11 Handheld hammer | 1 | 1.8 cm³ | 2.2 g | on its side — optional |
| **Total** | | | **144 g** | ~48 m of 1.75 mm |

PLA at 1.24 g/cm³ and 100% infill — the figures are solid volume, so
real filament use at 20–30% infill will be well under half of this.

**Nothing needs support.** The cross-bolt holes are teardrops for that
reason, and the orientations above put a flat face on the bed. Part 11
is a handheld version of the hammer for tapping off the rig — skip it if
you do not want one.

**Three parts need a print pause**, as in Luca Jost's build video:

- **Slider** and **knob** each capture a leadscrew nut. Pause when the
  hex pocket is open but not yet roofed over, drop the nut in, resume.
  There is no way to fit them afterwards.
- The **knurl** prints first, on its own. The **knob handle** print is
  then paused and the knurl slid onto its pin before the retaining
  flange prints over it. The flange is wider than the knurl bore, so
  again there is no fitting it later.

## Hardware

| item | size | qty | notes |
|---|---|---|---|
| Guide rod, aluminium | ⌀10 × 300 mm | 2 | ground or drawn, straight matters more than the grade |
| Linear bearing | LM10UU (⌀10 bore, ⌀19 OD, 29 long) | 2 | press fit into the slider, no clearance |
| Threaded rod | M8 × 312 mm | 1 | the leadscrew; cut from stock |
| Thrust bearing | 6200 (⌀8 bore, ⌀22 OD, 7 wide) | 2 | one in the base, one in the top plate |
| Cap screw | M4 × 10 | 4 | rod clamps, two per plate. **The length must be exactly this** — shorter misses the nut, longer bottoms out against the print |
| Nut | M4 | 4 | drops into the clamp slots from below |
| Nut | M8 | 1 | the drive nut, embedded in the slider mid-print |
| Locking nut | M8 | 3 | one captive in the knob, two setting the leadscrew's end float |
| Screw | M3 × 16–20 | 3 | **bolts the base to a board** — see below |
| Grub screw, M4 × 5, **cone point** | M4 | 2 | **the hammer's pivot** — one into each fork prong, see below |

## Electronics

Unchanged from Luca Jost's original — his [README][upstream] has
purchase links for all of it.

| item | qty |
|---|---|
| Electret microphone, 9.7 × 4.7 mm | 2 |
| Electret microphone, 6 × 2.7 mm | 2 |
| Behringer UCA-202 audio interface | 1 |
| Cinch (RCA) plugs | 4 |
| 4.7 kΩ resistors | 2 |
| 1 µF ceramic capacitors | 2 |
| 0.14 mm² wire, ~200 mm lengths | 8 |
| Thin wire, e.g. 34 AWG, ~10 mm | 4 |

Consumables: solder, flux, heat-shrink, two-part epoxy.

## Notes

**You will bolt it to a board.** The three M3 screws are not optional.
Free-standing this rig tips under about 56 g applied to the end of the
arm — a hand resting on it. The base's three counterbored holes take M3
screws into a board or the bench; bolted down it is nowhere near its
limit. Same is true of the original violin rig.

**The two M4 grub screws are the hammer's pivot.** One threads into
each fork prong, and their cone points seat in the rim of the 1.5 mm
hole through the hammer's tail — so the hammer hangs on two cones
rather than turning on a pin. That is about as little friction as a
printed pivot can have, which is the point: a stiff pivot damps the
impulse you are trying to measure. Wind them in until the hammer just
swings freely, which is also what stops them working loose.

The prong holes are printed at 3.93, undersize for M4, so each screw
cuts its own thread. Buy the tapered-tip ones — a flat or cup point
has nothing to seat in.

**The microphone lead runs through the slider.** A 3.5 mm bore enters
the carriage's front face through a cone of exactly 15 degrees, so the
lead is led in rather than chafed on an edge, and runs out along the
arm to the fork with its axis at mid thickness the whole way. Earlier
versions of this rebuild stopped that bore short of the face, leaving
the lead nowhere to go.

## What differs from the violin build

| | violin | this rig |
|---|---|---|
| guide rods | ⌀10 × 200 | **⌀10 × 300** |
| linear bearings | LM10UU | LM10UU |
| leadscrew | M8 × 212 | **M8 × 312** |
| thrust bearings | 608 (⌀22) | 608 (⌀22) |
| clamp hardware | M4 × 10 | M4 × 10 |
| column height | 200 mm | **300 mm** |
| filament | ~94 g | ~144 g |

Bold marks the only things that change. This rebuild used to step
the rods and leadscrew up with reach; working out where the movement at
the tap point actually comes from (`tools/stiffness.py`) showed the
printed arm accounts for 91% of it and the rods for 9%, so the step
bought almost nothing and has been removed.

[upstream]: https://github.com/luca-jost-violins/General-Acoustic-Measurement-Setup

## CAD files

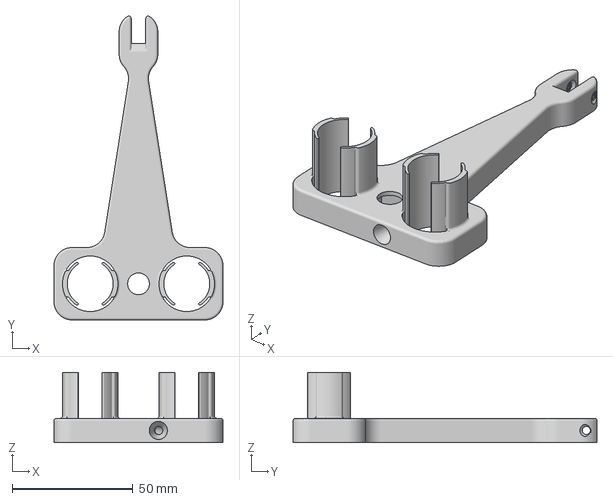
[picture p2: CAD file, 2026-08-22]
ref/upstream/03 Slider.3mf
70.0 x 125.9 x 29.0 mm

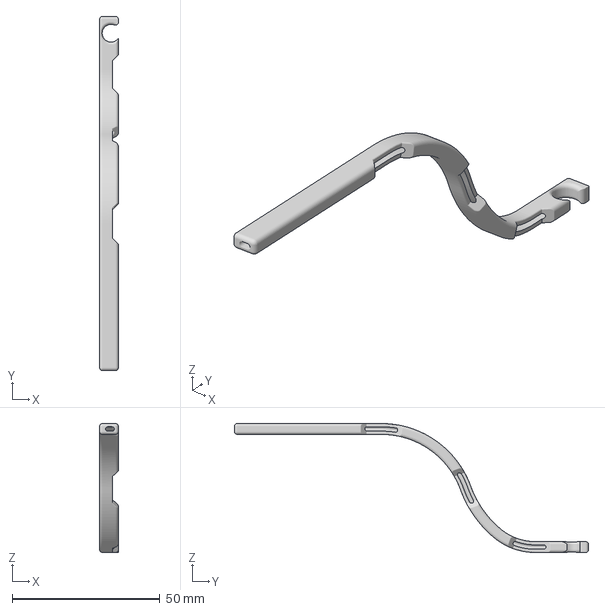
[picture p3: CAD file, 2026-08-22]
ref/upstream/Microphone arm/05 Microphoneholder + 0.15 mm.3mf
6.40 x 120.0 x 43.7 mm

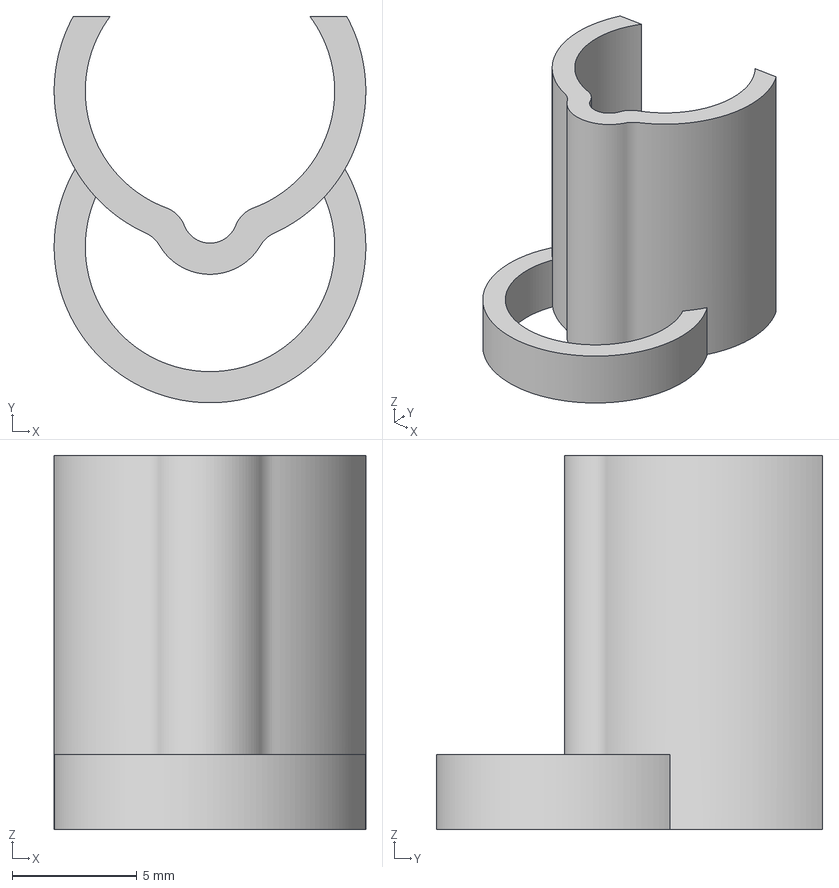
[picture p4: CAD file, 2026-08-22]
ref/upstream/06 Cable Management Clip.3mf
12.5 x 15.5 x 15.0 mm

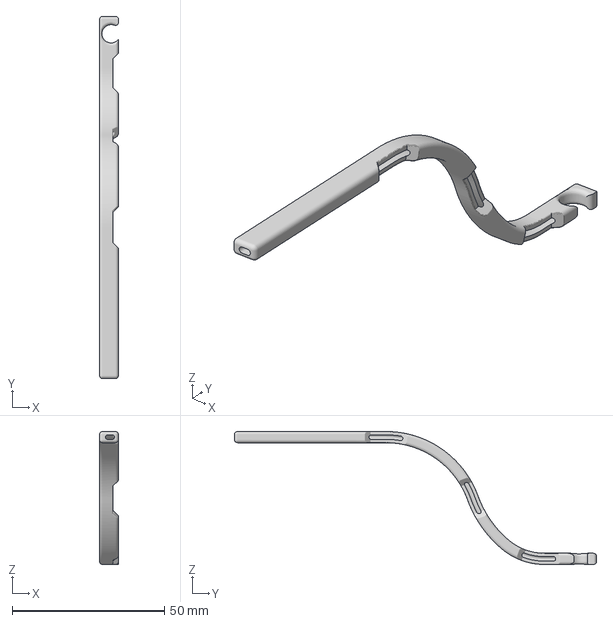
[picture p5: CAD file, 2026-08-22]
ref/upstream/Microphone arm/05 Microphone arm.3mf
6.25 x 119.0 x 43.7 mm

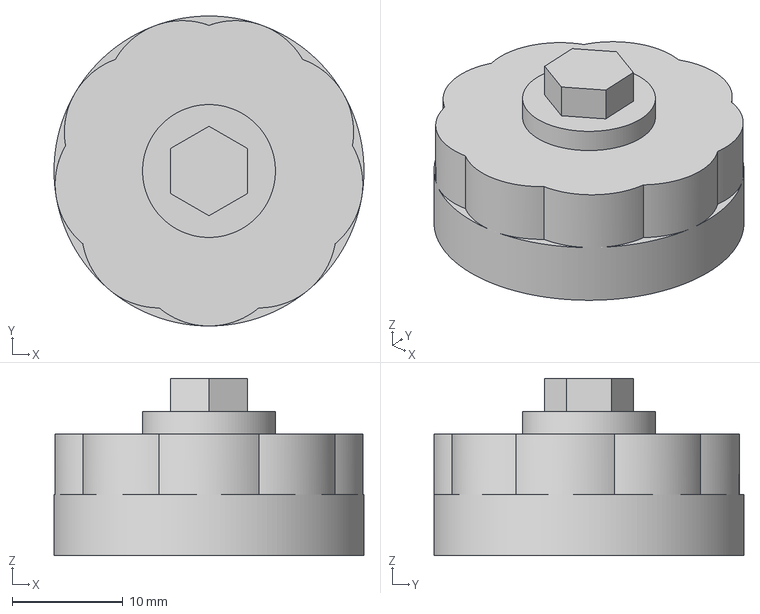
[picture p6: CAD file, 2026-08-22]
ref/upstream/08 Knob.3mf
28.0 x 28.0 x 16.0 mm

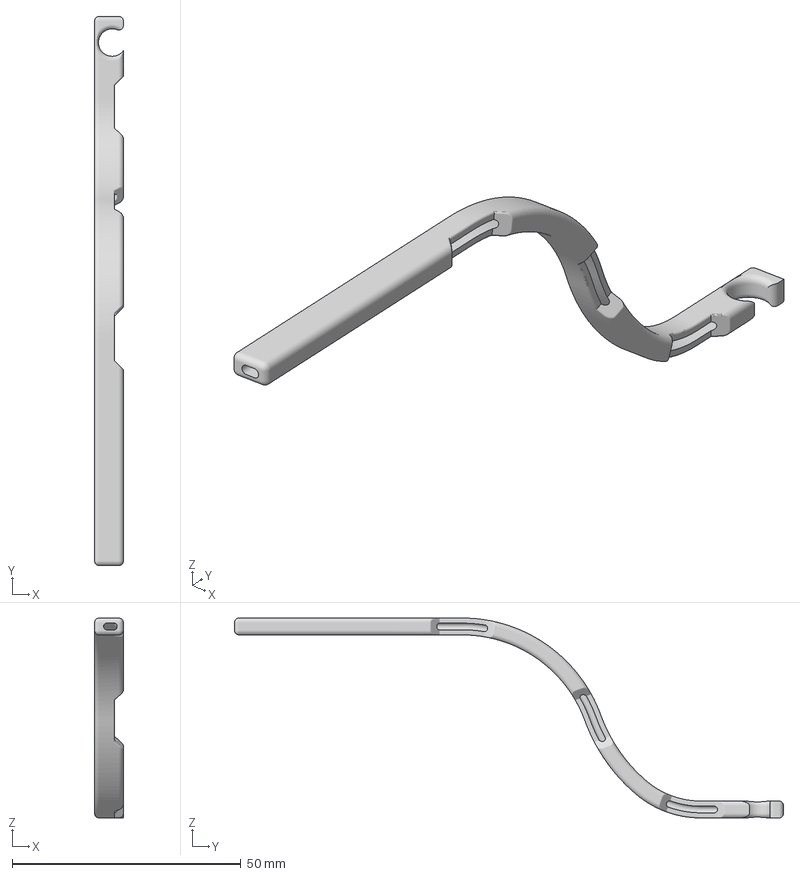
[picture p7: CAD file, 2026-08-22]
ref/upstream/Microphone arm/05 Microphoneholder + 0.05 mm.3mf
6.30 x 120.0 x 43.7 mm

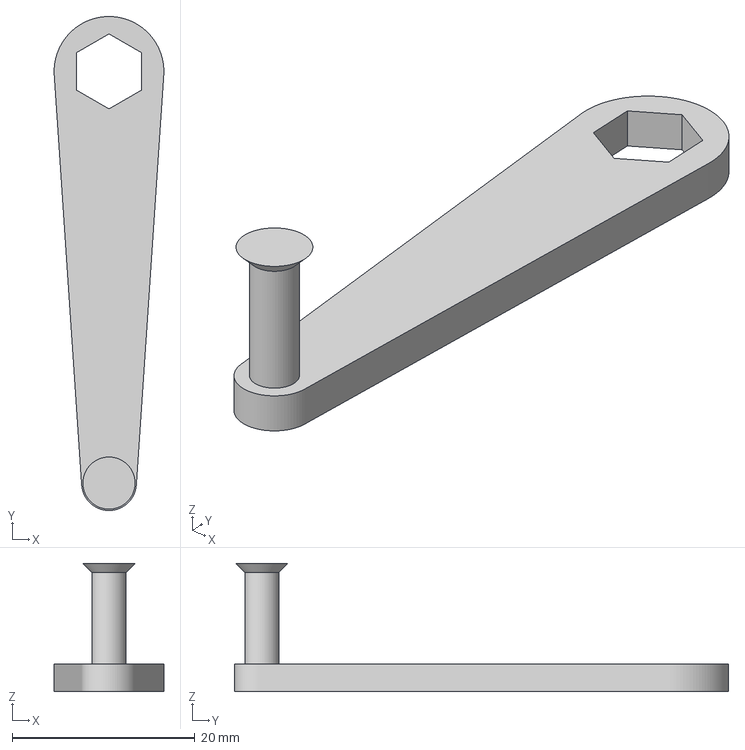
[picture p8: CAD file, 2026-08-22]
ref/upstream/09 Knobhandle.3mf
12.0 x 54.0 x 14.0 mm

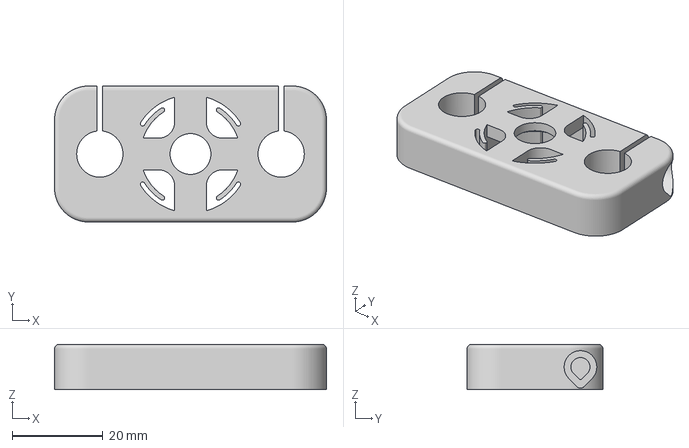
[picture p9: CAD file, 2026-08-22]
ref/upstream/02 Top.3mf
60.0 x 30.0 x 10.0 mm

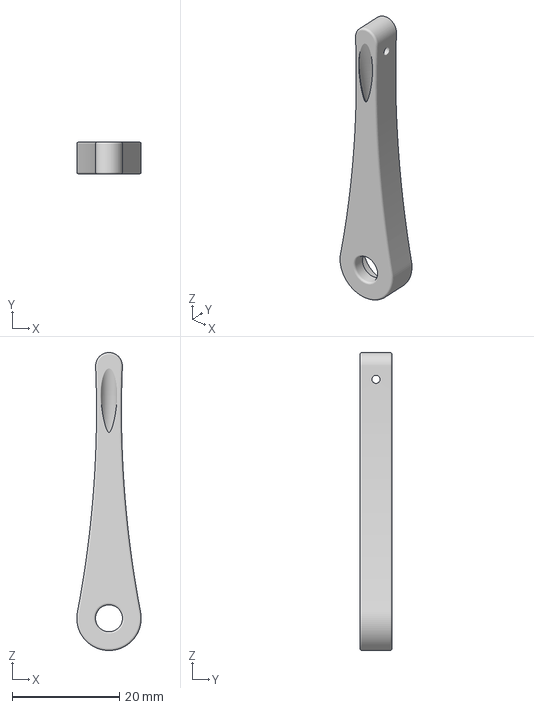
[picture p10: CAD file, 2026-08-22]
ref/upstream/07 Hammer.3mf
12.0 x 6.00 x 55.5 mm

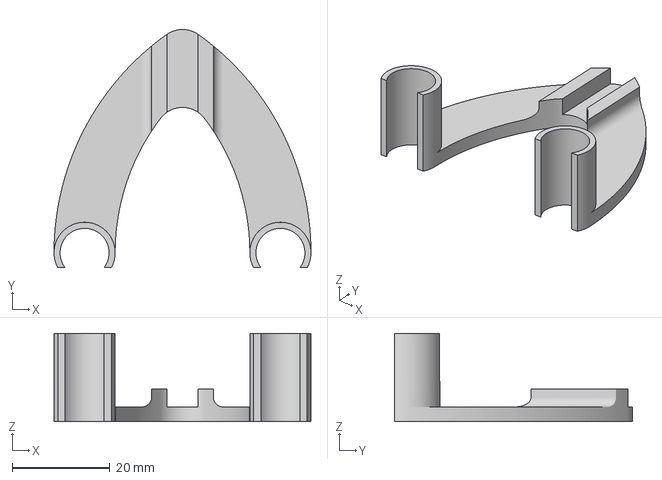
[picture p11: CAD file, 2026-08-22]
ref/upstream/04 Microphone holder.3mf
52.5 x 48.6 x 18.0 mm

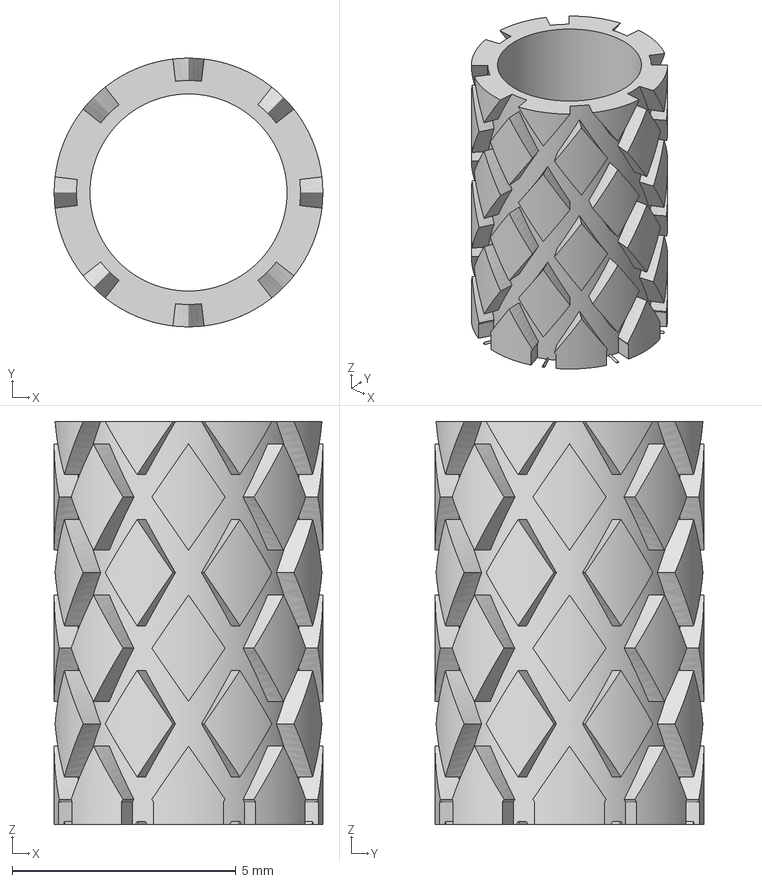
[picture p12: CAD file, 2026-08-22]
ref/upstream/10 Knobhandleknurl.3mf
6.00 x 6.00 x 9.00 mm

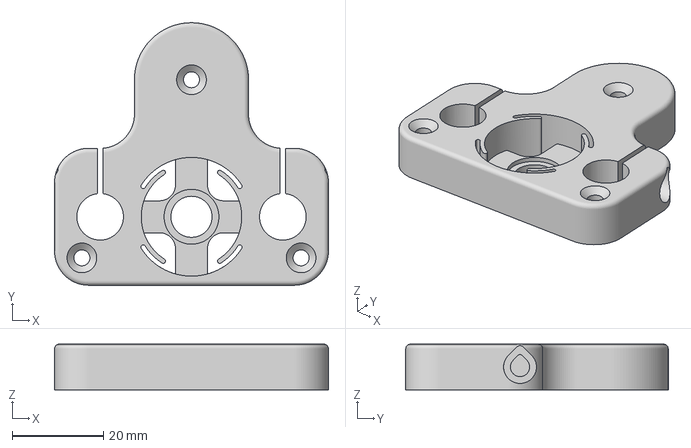
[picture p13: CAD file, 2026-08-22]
ref/upstream/01 Base.3mf
60.0 x 57.5 x 10.0 mm

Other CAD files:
ref/upstream/Microphone arm/05 Microphoneholder + 0.10 mm.3mf
ref/upstream/11 Handheld Hammer.3mf
ref/upstream/Microphone arm/05 Microphoneholder - 0.05 mm.3mf
ref/upstream/Microphone arm/05 Microphoneholder - 0.10 mm.3mf
ref/upstream/Microphone arm/05 Microphoneholder - 0.15 mm.3mf

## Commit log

2026-08-22 Reference capture and reverse-engineering tooling
    Vendored the upstream GAMS .3mf parts (MIT) and added tools to read them:
    mesh probe, STL export, 3D render and cross-section/circle extraction.
    Wired up build123d-mcp and cad-fingerprint for the rebuild.
    [01 Base.3mf, 01_base.stl, 02 Top.3mf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]
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2026-08-22 Reproduce the reference base lightening and bearing seat
    Adds the cad-fingerprint loop: tests/fingerprint/test_01_base.py is generated
    from ref/stl/01_base.stl and satisfied by the violin preset, plus tools to read
    the reference back (occupancy maps, part-vs-reference diff, arc decomposition).
    Corrects the base against the reference: bearing pocket is a zero-clearance
    22.0 seat exactly 7 deep, the outrigger neck is straight rather than flared,
    and the plate is lightened by four annular sectors between four 7 mm webs,
    crossed by a thin stiffening rib. Fingerprint failures 41 -> 24, volume error
    7.5% -> 4.4%, Hausdorff 2.52 -> 2.26 mm.
2026-08-22 Base matches the reference to 0.05% by volume
    Corrects three things measured off the reference mesh: the plate corners are
    rounded 7.5 not 5.0, the top perimeter carries a 1.0 break, and the bearing
    seat is a rim-sized disc flatted to 22.0 across X so the flats locate the
    bearing. The lightening is a brace sweeping between the spokes with a radial
    spur tying it back to the rim.
    Violin preset volume 16741.3 vs reference 16749.2 (-0.05%). Fingerprint
    failures 41 -> 39, with volume, surface area, centre of mass and mean surface
    deviation all now passing.
2026-08-22 Add the top plate, and share the column geometry with the base
    Extracts src/gams/column.py: the split rod clamp, the lightened hub and the
    bearing seat are common to both plates. The top differs only in which face the
    seat opens from and in printing inverted, so its cross-bolt teardrops point the
    other way.
    Four corrections found while fitting the top, all of which also improve the
    base:
    - the clamp nut slot runs 7.46 deep, not to the bolt axis
    - the cross bolt is counterbored 7.3 x 5.0 so the cap head seats flat in the
    curved outer face, and starts 8 in from the rod centre
    - the lightening is mirror-symmetric about both axes, not four-fold rotational
    - the brace runs the full thickness,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
    [02_top_local.stl]
2026-08-22 Add the slider, and fix the nut table for M10 leadscrews
    The slider is the part that sets the tap point: two linear bearings on the
    rods, a captive drive nut, and a tapered arm carrying the hammer fork. Its
    derived dimensions all fall out of the parameter set already in place — tube OD
    23.0, carriage 70 x 30, bearing tubes 29 tall, and the pivot on the instrument
    centreline at Y = reach.
    Volume is +11% against the reference and the arm's internal geometry is only
    partly recovered, so this is a first pass rather than a match. What is right:
    the envelope, the zero-clearance 19.0 bearing bores, the hex drive-nut pocket,
    the bore reliefs that leave four posts, and the offset core running alon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
    [03_slider_local.stl]
2026-08-22 Slider within 1% of the reference, and scaling fixed for the larger presets
    Three corrections: make_hull was convexifying the arm's waist away, so the arm
    was a straight wedge instead of necking down at 0.755 of reach; the fork head
    sits 2.51 behind the pivot, which puts the prong tips at 110.906 against the
    reference's 110.903; and each bearing post is L-shaped in section, wide where
    it wraps the bearing and stepping in at the rim, rather than a plain sector.
    Volume -11.24% -> -0.80%.
    The arm taper and the post step were absolute values tuned for the violin, so
    the bass viol arm tapered to a negative width and would not build. Both are now
    proportional, which is also the right structural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
2026-08-22 Add the knob, crank handle and spinning grip
    All three within 2% of the reference: knob +1.45%, handle -0.27%, grip +1.90%.
    The knob traps an M8 nut in its underside and carries a hex post on top; the
    crank arm sockets onto that post with 0.11 clearance and tapers 12 -> 6 on
    tangent flanks to a pin, which carries a 16-flute sleeve retained by a flange
    so it spins under your fingers. Tests assert those three fits rather than just
    the shapes.
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2026-08-22 Add the microphone arm — all eleven parts now within 1.9%
    The arm is a hollow strut swept along a straight/S-bend/straight path from its
    clamp on the column out to the microphone at (mic_reach, 14.34). The cable runs
    inside it, which is the point: a lead flapping in free air adds its own damping
    to the measurement.
    Two things that mattered: a single spline through all four path points
    overshoots above the root and makes the arm taller than it is, so the straights
    are lines and only the bend is a spline; and the swept section needs its plane
    pinned with x_dir or it comes out rotated 90 degrees.
    The real arm tapers along its length and this one does not — envelope, path,
    channel and volu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
2026-08-22 Correct the microphone arm: closed box with two access windows, obround section
    The arm does not taper, and it is not an open channel. Three corrections, all
    found by comparing section outlines rather than areas:
    - the outer section is an obround, ends fully rounded at t/2, not a rounded
    rectangle — that alone is ~9% of the arm's volume
    - the +X wall is removed only in two short windows (Y 58.5..70.5 and
    109.5..120.5) so the cable can be laid in from the side
    - everywhere else, including the whole S-bend, the section stays a closed box
    That last point is the one that matters: an open section is far softer in twist
    than a closed one, and the original keeps the box closed exactly where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
    [05_mic_arm.stl]
2026-08-22 Add the assembly, and correct what the microphone holder actually grips
    assembly.py places every part at the offset the upstream .3mf files already
    imply — base Z 0, holder 49.5, slider 95, top 190, knob 202 — plus the rods,
    leadscrew and bearings so the fits are visible. Exports as a labelled STEP.
    The slider and hammer are no longer placed by hand: the hammer hangs on the pin
    through the slider fork, so the slider height follows from where the belly is
    and the hammer follows the slider. That is why the assembly puts the tap point
    at 45.0 rather than the reference's 49.5 — a crank position, not a dimension.
    Also corrects a real misreading: the holder's fins grip the microphone *arm*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
2026-08-22 Make the microphone subsystem scale — the gamba assemblies were broken
    The arm and holder were the last parts still carrying absolute dimensions, so
    on the bass viol the arm sat at violin height on a 300 mm column and the holder
    floated 50 mm away from it. Both now derive: arm section from mic reach, arm
    root from the tap point, holder height from where the fins have to meet the arm,
    and the arch, slot, fin and crank dimensions from the parts they mate with.
    Two failures only the gamba presets could reveal:
    - the traced bend table's Y values are fractions of reach, so deriving
    mic_arm_bend_from did nothing until the table was remapped onto each rig's
    own bend — before that the bass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
2026-08-22 Analyse centre of gravity and stability across all presets
    tools/stability.py computes the assembly CoG with real densities (PLA,
    aluminium rods, steel leadscrew and bearings) and checks it against the
    triangle of mounting points, plus the loads that tip the rig.
    The bass viol is the most stable of the five, not the least — the outrigger
    scaling with reach works, and the static margin grows from 12.7 mm on the
    violin to 21.4 mm.
    The more useful finding is that every preset tips under 48-123 g applied to the
    arm tip. Since the violin preset reproduces upstream, that is true of the
    original rig too. It resolves what the three mounting points are for: 3.5 mm
    holes with a 5.5 x 1.0 spotface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
2026-08-22 Prepare for publication: drop derived files, make the default test run clean
    Untracks ref/stl, ref/render and ref/section — 13 MB of STLs, renders and
    section plots all regenerable from ref/upstream with the tools in tools/.
    ref/README.md documents how, and what each tool is for. Repository goes from
    17 MB to 4.3 MB tracked. ref/upstream stays: it is the reference everything was
    measured from, it is MIT, and it keeps the repo self-contained.
    Also excludes tests/fingerprint from the default pytest run. Those suites are a
    research record of how close the rebuild is to the original, and a handful fail
    by design — a visitor typing `pytest` should see the design suite pass, not 17
    documented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
    [01_base.stl, 02_top.stl, 02_top_local.stl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]
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2026-08-22 Add a bill of materials for the bass viol / cello rig
    BOM.md covers the combined rig: printed masses and orientations, exact bolt
    lengths, bearing designations, and what differs from a violin build. It is
    generated by tools/make_bom.py from the same parameters the parts are built
    from, so it cannot drift from the geometry — regenerate it for any instrument
    or combination.
    Everything in it is computed rather than assumed. The M5 clamp screws come out
    at 20 mm because the nut face sits 12.8 mm from the head seat and an M5 nut is
    4 thick; the leadscrew is 312 because that is where the knob's captive nut ends;
    LM16UU and 6200 fall out of the bearing sizes the parts are bored for.
    Two things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
2026-08-22 Correct an unfounded claim about the grub screws, and list every departure
    The BOM said the original's two M4 grub screws "are not needed" because the
    microphone arm is gripped by the holder's fins. That was wrong to assert. I
    never modelled grub screws and never checked whether the reference has them,
    then wrote the omission up as a design decision on a rig that has been built
    and iterated on in practice.
    What I can now show: the holder's fins are solid walls, no opening at any Y or
    Z, and there is none in the clip or the arm either. So friction grip is what
    his holder does. But that does not tell me what his two grub screws are for,
    and "I could not find their hole" is not "they are unnec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
2026-08-22 Correct the build against Luca Jost's own assembly video
    Went through the captions of "Making the General Acoustic Measurement Setup"
    against the model. Five things were wrong or missing:
    1. The two M4 grub screws retain the linear bearings in the slider. His slider
    has an M4 tapping-size hole through a bearing tube's inboard wall; this
    model has none, so a slider printed from it holds its bearings by press fit
    alone. Documented, not yet modelled — I have located one hole confidently
    and not the second.
    2. The clamp bolt length was wrong, and dangerously so. He warns the M4 must be
    exactly 10 mm: shorter misses the nut, longer bottoms out against the print.
    The BOM spec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
2026-08-22 Retract a wrong claim about the grub screw hole
    I identified a bore in the slider as the M4 grub screw hole, documented it, and
    drew a diagram of it. It is the cable channel. Tracing it along Y shows a
    continuous 3.5 mm void running from the front face of the carriage all the way
    out along the arm, its centre drifting X 8.55 -> 1.28 between Y=0 and Y=60 —
    which is the arm's diagonal core, measured earlier in this project. The conical
    mouth at the front face is a lead-in for the microphone lead, not a screw seat.
    The bearing tube walls are solid at every height from Z=106 to 122, so there is
    no radial screw hole there either. I have not found where the grub screws go.
    Both BOM.md and the R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
2026-08-22 Rebuild the hammers from Luca Jost's actual arcs
    The outline is not a taper table: it is a 12 mm round head, a 5 mm round
    tail, and a 200 mm arc tangent to both, which fits his mesh to 0.002 mm.
    Inside, both parts are bored through the head with a recess on one face and
    run a channel from that bore up the shaft - round in part 07, a flattened
    slot in part 11 - straight to Z=36 then out through a face on a 38 mm arc.
    Volume goes from +1.1% to -0.14%, and the length from 55.45 to the correct
    55.50. What was modelled as a fork through the head was in fact a plain bore
    with a counterbore, and the core was centred when it is offset 1 mm.
    Cla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
2026-08-22 Rebuild the microphone arm section, bend and tip
    Three errors, all found by fingerprinting the part rather than weighing it.
    The section shapes were swapped: the outer is a rounded rectangle 6.25 x 3.70
    with a 1.00 corner, and the channel inside it the obround, 3.00 x 1.50 offset
    0.30 off centre. Having it the other way round cost 9% of the section area.
    The S-bend is an arc, a straight and a second arc, tangent throughout - R29.6,
    62.6 degrees, R23.8. That fits his centreline to 0.33 mm where the 22-point
    traced table it replaces managed 0.70, and it has real tangents, so the swept
    section cannot wobble between samples.
    The tip carries a plain 6 mm hole for the electret in his bill of ma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
2026-08-22 Correct the crank pin head and make the sleeve a diamond knurl
    The pin is 3.70 with a cone head flaring to 5.70 over the last millimetre,
    not a 3.64 pin with a disc: measured off the reference, where the handle now
    matches to +0.03% and fills the same bounding box exactly.
    The sleeve is knurled, not fluted. Unwrapping its surface shows two families
    of eight helical grooves running opposite ways and crossing - a diamond
    pattern. Straight flutes gave about the right volume and the wrong grip,
    since fingers slide along a flute, which is the one direction it has to hold.
    Modelled as the intersection of two twisted extrusions, the way the real
    thing is cut.
    Fingerprint failures: handle 36 -> 15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
2026-08-22 Correct the slider's reach, fork head and cable channel
    The reference's hammer pivot bore is at Y=106.5 on a 208 mm bout, so the
    column gap is 2.5 and not 2.0. That half millimetre moves the tap point,
    which is the whole geometry of the rig, so it is worth having right.
    The fork head is a truncated round: R8 centred 2.30 behind the pivot and cut
    flat 4.40 ahead of it, where I had a full round 2.51 behind. Its slot floor
    is 8.9 behind the pivot, not 16.
    The arm is not a hollow box beam. It carries a single 3.50 mm bore for the
    microphone lead, entering the carriage's front face through a cone whose
    half-angle is exactly 15 degrees and running out to the fork with its axis at
    mid thickness t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
2026-08-22 Add the thrust bearing relief and a teardrop counterbore
    Both plates step the central bore three ways, not two: 22.00 for the thrust
    bearing, then 12.00 for a millimetre to clear its inner race, then 9.00 for
    the leadscrew. Without the relief the plate bears on the race the screw turns
    in, which loads the balls sideways and stiffens the crank.
    The clamp bolt's head counterbore is a teardrop in the reference, the same
    support-free trick as the bolt hole itself, and pointing the same way for
    each plate's print orientation.
    Two bugs found in cad-fingerprint while doing this, both filed:
    #5 cross-section area adds holes instead of subtracting them - a 20x20
    plate with a 10 mm hole repor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
2026-08-23 Widen the knob's flutes, and bring the docs up to the measurements
    The knob's knurl is nine broad scallops, not nine narrow grooves: the cutter
    is 2.68 mm where the cut is only 0.84 deep, which is what makes each flute
    something a finger sits in rather than catches on. Volume +1.45% -> +0.44%,
    and its mass properties now agree.
    Docs updated to what is actually true now. The cable route through the
    slider, which this repo has been documenting as a known gap, is modelled.
    Every part is within 0.6% by volume, worst case, against 1.9% before - but
    the README now says plainly that volume is the weak test and points at the
    fingerprint suites instead, since that was the mistake that let the earlie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
2026-08-23 Note what the arch's semi-width is, and why it is not free
    Tried refitting the holder's outer superellipse with its semi-width free: it
    follows his outline better on paper (0.77 mm against 1.02) and is wrong,
    because the part measures exactly 52.50 across and a free fit does not. The
    semi-width is his; only the height and exponent are mine. Reverted, with the
    constraint written down so the next attempt does not repeat it.
    Claude-Session: https://claude.ai/code/session_01CB3icQ2smFgrNqudPxA3cB
2026-08-23 Add tools/report.py, so a passing part reports a number too
    The generated suites only print a value when a check fails, which makes them
    poor at showing how much room a part has. This calls the same routines
    directly and reads each suite's own tolerances - which differ part to part,
    because cad-fingerprint scales them by how well that reference mesh decimated,
    not by anything to do with the part.
    Cross-sections and the radial profile are deliberately absent: both measure
    the wrong thing, filed as cad-fingerprint #5 and #6.
    Its output is gitignored. A committed snapshot would drift away from the
    model and be believed anyway.
    Claude-Sess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
2026-08-23 Give the clamp nut slot the gabled end it actually has
    Its far end is not flat: it closes as a 30 degree gable, so the nut meets a
    wedge and settles onto the bolt axis instead of sitting anywhere across the
    slot's width. And the slot is deeper than I had it - 9.19 of the plate's 10,
    leaving 0.81 over the nut rather than 2.54.
    Both plates use the same cutter, so both moved. Top: Hausdorff 1.518 -> 0.433,
    mean deviation 0.017 -> 0.011, centre of mass 0.039 -> 0.009, principal
    moments 0.55% -> 0.10%. Base: 1.074 -> 0.804, and it now passes every honest
    check.
    The top still exceeds its 0.30 tolerance on worst-case deviation, at 0.433
    with a 95th percentile of 0.16. What is left is the exact sh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
2026-08-23 Strike the teardrops as tangents, not as triangles from the diameter
    Both holes in the rod clamps are teardrops so they print without support, and
    the shape of one is not a matter of taste: the sides have to be tangent to the
    hole and at 45 degrees, the steepest overhang a printer bridges unsupported.
    Luca Jost drew them that way. I had a triangle from the hole's diameter to a
    point, which gives sides at whatever angle the apex constant happened to set -
    34 degrees as it stood, so the widths came out wrong all the way down.
    Measured against his counterbore the sides now rise exactly 1.0 in width per
    1.0 in height, as his do. Two clearances came out of that measurement and are
    now his rather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
2026-08-23 Measure the sleeve's knurl helix instead of guessing at it
    Unwrapping his surface and shearing it until the helices line up gives the
    rate directly: 13.5 degrees per millimetre, 121.5 over the sleeve's height,
    where I had 66.2 - not quite half. The same map gives eight starts on a 45
    degree pitch with a 14 degree groove, all of which I now match, along with
    the root at 2.50, the crest at 3.00 and the volume to +0.10%.
    It is still outside its surface tolerance: 0.379 mm worst case against 0.300,
    and 0.090 mean against 0.050. Rate, count, pitch, width and depth are all his
    now, so what is left is the shape of the groove in section - most likely
    rounding at its corners that my flat-bottomed we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
2026-08-23 Slide the sleeve's knurl lattice to where his sits
    Spotted by eye in the STEP: little tabs of material hanging off the top rim.
    They are not a modelling artefact but a phase error - a row of diamond
    crossings was landing exactly on the rim, where his sits 0.9 mm lower.
    Skewing one helix family against the other slides the lattice along the height
    without moving it round the part, which is the control that was missing. At
    120 degrees of twist and -15 of skew the pattern agrees with his over 98.5% of
    the surface, against 63.7% before, and the rim now has the same eight islands
    of the same widths at every height I sampled.
    Surface deviation 0.360 -> 0.278 against a 0.300 tolerance and 0.075 -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
2026-08-23 Bring the docs up to eleven of eleven
    The knurled sleeve passes now, so it comes out of the list of departures and
    into the list of things measurement turned up: the diamond is two families of
    eight grooves crossing at 13.3 degrees of twist per millimetre, and where the
    crossings sit along the height matters - put them on the top rim and you get
    tabs of material hanging off it.
    The BOM's note about the missing cable route was stale in the generator, so it
    came back every time the file was regenerated. Fixed at the source rather than
    in the output.
    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
2026-08-23 Delete the hardware ladder - it did not survive being checked
    Every preset now runs on Luca Jost's hardware: 10 mm rods, LM10UU bearings, an
    M8 leadscrew and 608 thrust bearings. Only the rod length changes with the
    instrument.
    The ladder stepped rods and leadscrew up with reach, on the argument that a
    printed cantilever on 10 mm rods deflects enough at a cello's reach to move
    the tap point between taps. tools/stiffness.py, added here, works out where
    that movement actually comes from: at that reach the printed slider arm
    accounts for 91% of it and the rods for 9%. Going to 16 mm buys 31 microns out
    of 434.
    In stiffness the arm is 1.9 N/mm at the tap point and the 10 mm rods 19.3 -
    springs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
2026-08-23 Render the hero properly: PBR, image-based lighting, blue PLA
    The old picture went through matplotlib, which has no depth buffer, so it came
    out flat. The MCP viewer is better lit but gives no control of resolution,
    background or materials, and its output was still washed out.
    This drives VTK directly: physically-based materials, an environment light
    built from a procedural sky, and printed parts, aluminium and steel given
    their own colour, metallic and roughness so a rod reads as a rod. Dark blue
    PLA against the aluminium, which is what the pale version was missing.
    Two things deliberately left out. VTK's shadow-map pass clips this geometry,
    and its screen-space occlusion speckles the thi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
2026-08-23 Add tools/printability.py: does every part fit the printer?
    The slider's arm and the microphone arm both grow with reach, so the large
    presets are the ones at risk of running off the bed. This checks every part of
    every preset against a declared build volume, allowing for turning a part
    diagonally, and names anything that only fits that way.
    On a 256 cube every part of every preset fits flat. The tightest is the cello
    slider at 241.9 x 70.0 x 29.0, which is 97% of the bed once a margin is left
    for the purge line.
    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
2026-08-23 The two M4 grub screws are the hammer's pivot
    Paul spotted it: they form a hinge between the fork and the hammer. The
    geometry agrees on every count.
    fork prong hole 3.925 right through - under M4's 4.0 major diameter, so
    the screw cuts its own thread rather than clearing it
    prong thickness 4.705, so an M4 x 5 stands 0.295 proud of the inner face
    hammer's hole 1.496 through - far too small for a bolt; it is a seat
    for the cone tips
    both coaxial on X at Y=106.5, Z=5.0
    The hammer hangs on two cone points, not on a pin. That explains everything
    about them I had found separately and could not account for: why its hole is
    only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
